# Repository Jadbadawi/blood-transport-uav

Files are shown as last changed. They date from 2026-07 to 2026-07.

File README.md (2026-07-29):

<div align="center">

# Blood-Transport UAV — Joints & Fairings

### Every structural interface that holds the aircraft together, and every aerodynamic surface that covers them

**AVDASI 2 · University of Bristol · Department of Aerospace Engineering · 2024–25**
Albatross Aviation (Company A) · Team 08 · Fuselage Division








</div>

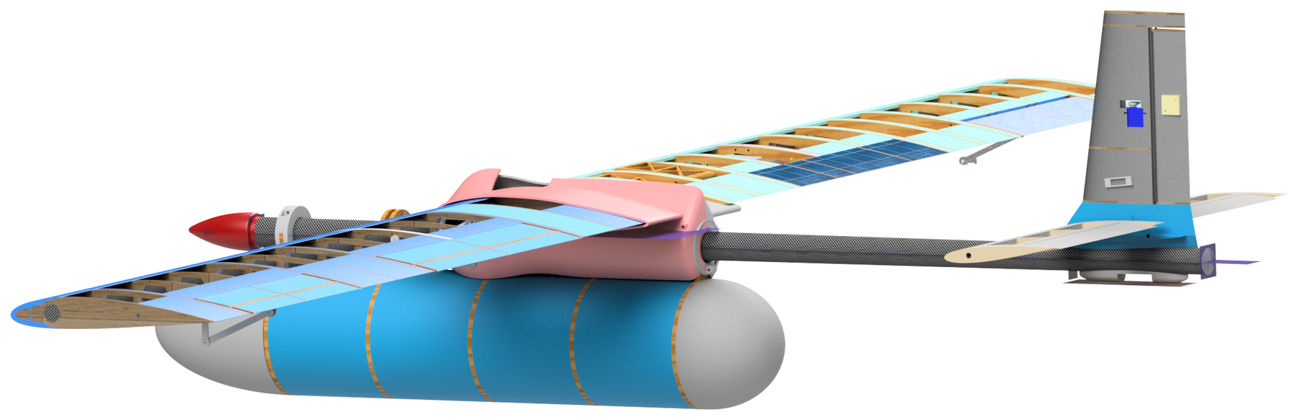
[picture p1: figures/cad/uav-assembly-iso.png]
The UAV as assembled in CAD


<div align="center"><sub><b>Full-vehicle CAD assembly.</b> The pink structure over the wing root is the Fus-MWP fairing; the joint beneath it, the empennage joint at the tail and every fairing on the aircraft are this team's work.</sub></div>

---

## The brief

Design, build and test a UAV capable of moving blood samples rapidly between a rural short
tarmac runway and a hospital test centre — the outbound leg is time-critical, the return by
road is not. Sixty students, three competing companies, one academic year, and a real test
campaign at the end: a wind tunnel entry for aerodynamic data and a load test taken past
the ultimate load case.

Team 08 owned the **joints and fairings** — every structural interface that holds the
aircraft together, and every aerodynamic surface that covers those interfaces. That put us
downstream of six other teams and upstream of the whole airframe: **nothing assembled until
our parts fit.**

**My role:** Fuselage Division Design Team Manager, Team Project Manager, Aero Specialist
and Design Specialist. → [What I personally did](docs/my-contribution.md)

---

## Results at a glance

| | |
|---|---|
| **Ultimate load test** | Survived to **813 N**, past the required ultimate load case |
| **Load response** | Linear throughout — **74 N/mm** centre, **102 N/mm** empennage, no stiffness knee |
| **Governing reserve factor** | **1.95** — 22.2 mm centre bar in bending, at 6g × 1.5 |
| **Observed failure** | Bolt shear-out through the PLA main wing clamp — *an unmodelled path* |
| **Wind tunnel** | 20 m/s; fairings added **+0.09 N** drag, inside the 0.34 N run-to-run scatter |
| **Subassembly mass** | **1,011 g** across 10 parts; fairings were 11.85% of all-up UAV mass |
| **Parts delivered** | 10 flight parts, 100% additively manufactured |

<table>
<tr>
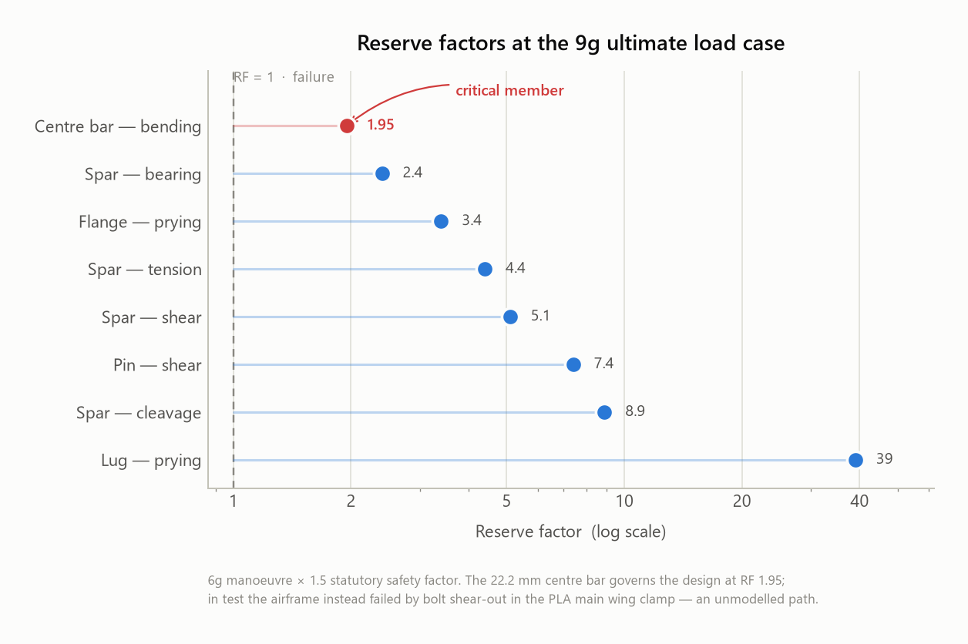
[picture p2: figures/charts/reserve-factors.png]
Reserve factors by check
<td width="50%"></td>
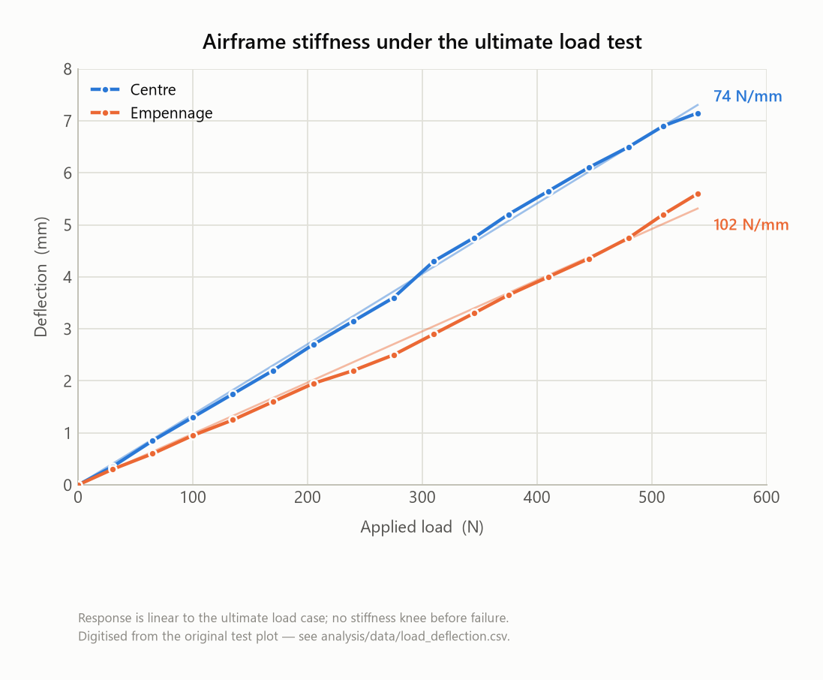
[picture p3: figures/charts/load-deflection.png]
Load vs deflection
<td width="50%"></td>
</tr>
<tr>
<td><sub><b>Eight reserve factors</b>, critical member highlighted. The centre bar at 1.95 was the predicted first failure.</sub></td>
<td><sub><b>Linear to ultimate load</b> — no knee, no progressive softening. The strongest single result in the project.</sub></td>
</tr>
</table>

**The headline engineering result is the gap between two rows of that table.** The stress
work predicted the centre bar would go first. It didn't — the aircraft failed somewhere the
analysis never looked, because no reserve factor had been computed for any 3D-printed part.
That finding, and what it says about where analysis boundaries get drawn, is the most useful
thing in this repository. It is worked through in
[**Structural analysis**](docs/04-structural-analysis.md) and
[**Test campaign**](docs/07-test-campaign.md).

---

## The aircraft

<table>
<tr>
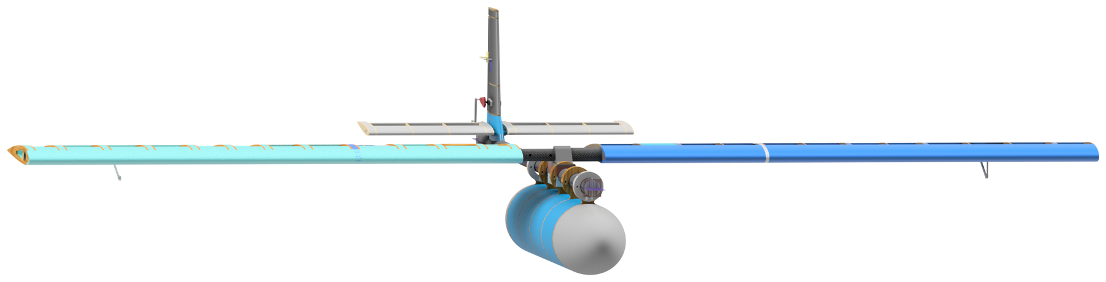
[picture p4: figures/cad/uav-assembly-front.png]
Front view
<td width="33%"></td>
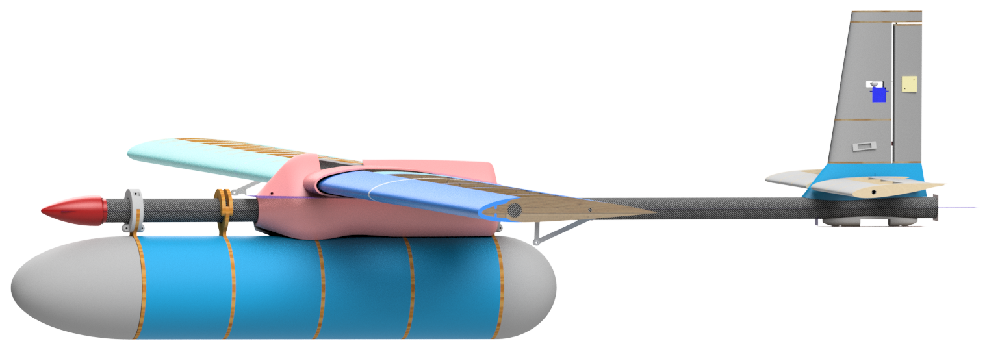
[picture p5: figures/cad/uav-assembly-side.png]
Side view
<td width="33%"></td>
<td width="33%">Isometric view</td>
</tr>
<tr>
<td align="center"><sub>Front</sub></td>
<td align="center"><sub>Side</sub></td>
<td align="center"><sub>Isometric</sub></td>
</tr>
</table>

A 535-file Inventor assembly, including other teams' geometry so the top-level assembly
resolves. Authorship is attributed per-tree in [`cad/README.md`](cad/README.md).

---

## What this team designed

Ten flight parts across two families: **structural joints** that carry load between major
assemblies, and **aerodynamic fairings** that cover the interfaces those joints create.

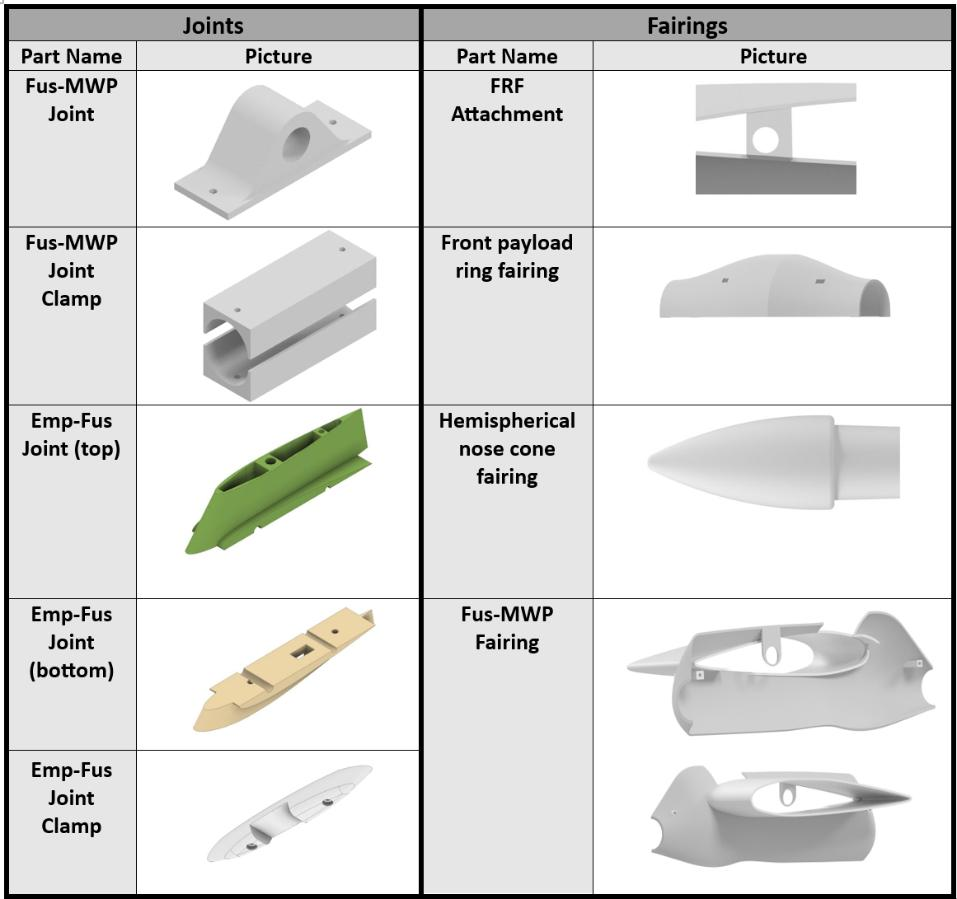
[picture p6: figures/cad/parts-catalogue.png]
The delivered part set


<sub><b>The delivered part catalogue.</b> Every part on this sheet was designed, printed, fitted and flown by Team 08.</sub>

### Structural joints

<table>
<tr>
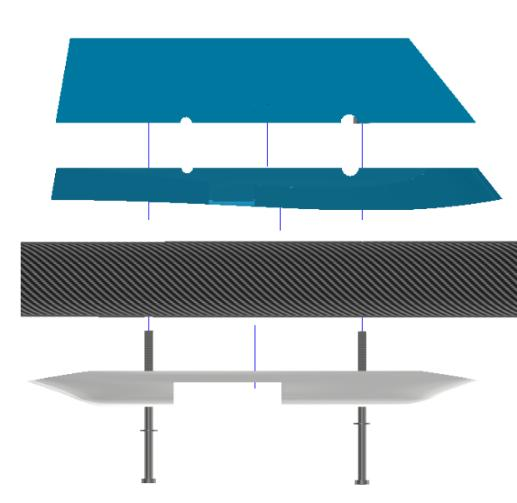
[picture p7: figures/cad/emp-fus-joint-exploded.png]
Empennage-fuselage joint, exploded
<td width="50%"></td>
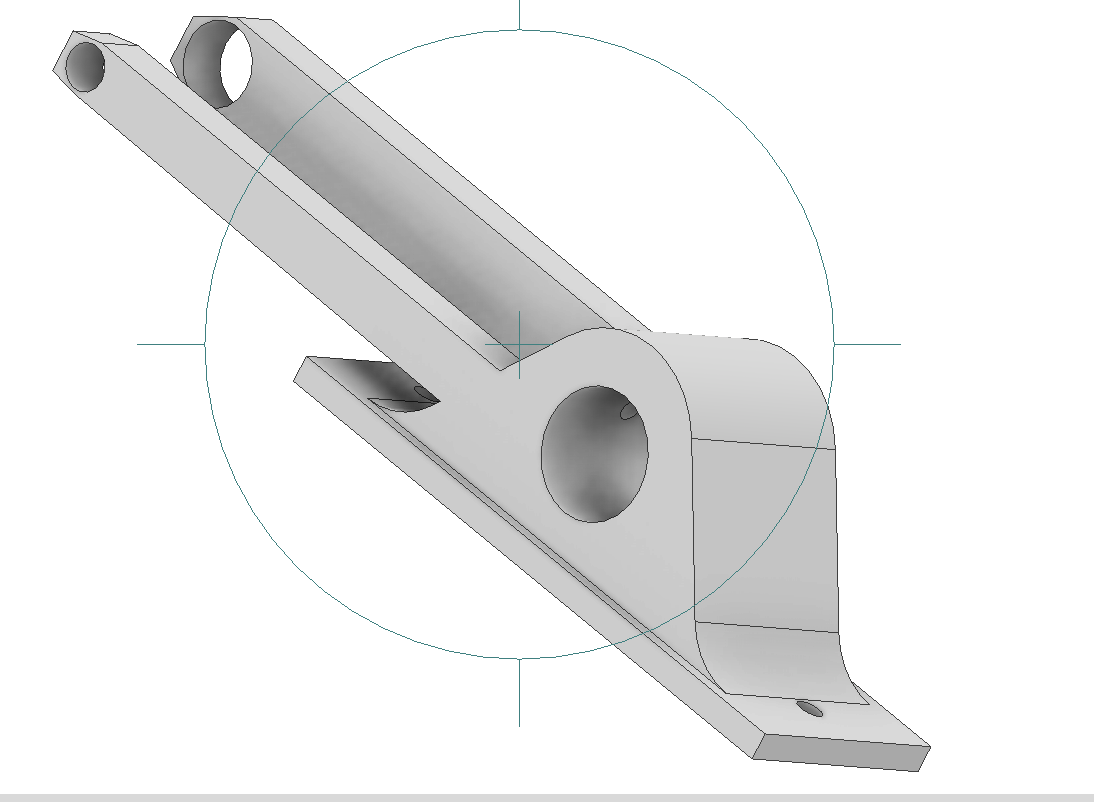
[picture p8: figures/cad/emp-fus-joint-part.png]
Empennage-fuselage joint part
<td width="50%"></td>
</tr>
<tr>
<td><sub><b>Empennage–fuselage joint, exploded.</b> Load passes predominantly into the CFRP fuselage spar, which is sized for it — so the unreinforced PLA joint is acceptable at these load cases.</sub></td>
<td><sub><b>The joint as a single part.</b> Brass inserts take the fasteners; these could work loose under significant lateral load, which the structural test never applied.</sub></td>
</tr>
</table>

<table>
<tr>
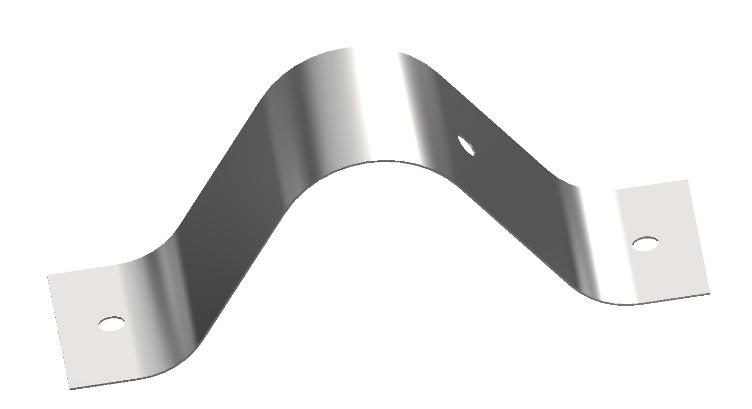
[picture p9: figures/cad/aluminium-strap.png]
Formed aluminium strap
<td width="50%"></td>
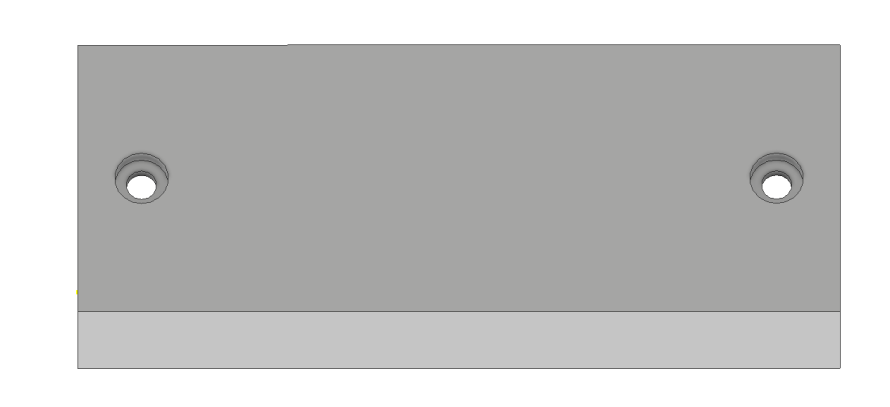
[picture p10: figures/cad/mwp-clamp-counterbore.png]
Main wing plane clamp counterbore
<td width="50%"></td>
</tr>
<tr>
<td><sub><b>Formed 2014A-T3 aluminium strap.</b> This is what protects the <i>upper</i> half of the Fus-MWP joint — load passes into metal and away from the printed plastic.</sub></td>
<td><sub><b>The clamp counterbore.</b> The <i>lower</i> clamp has no such protection, and bolt forces bear directly on PLA. This asymmetry is the direct cause of the eventual failure.</sub></td>
</tr>
</table>

> **The load-path asymmetry above is the whole story of this project in one pair of images.**
> The top half of the joint was protected by metal. The bottom half was not, and nobody
> modelled it.

### Aerodynamic fairings

<table>
<tr>
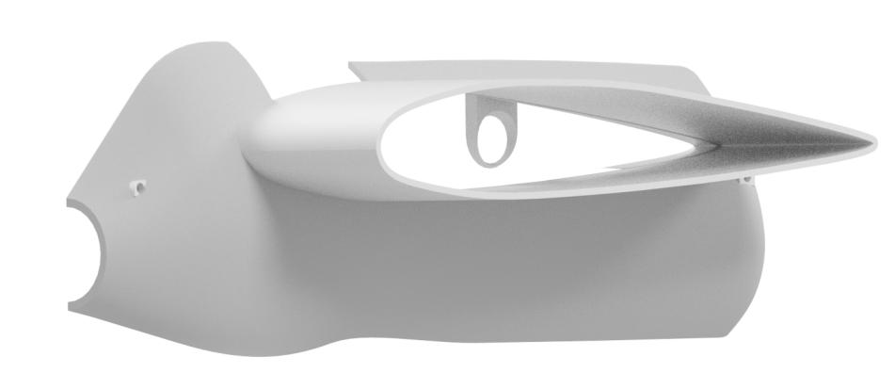
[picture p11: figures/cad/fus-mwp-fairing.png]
Fuselage-main wing plane fairing
<td width="50%"></td>
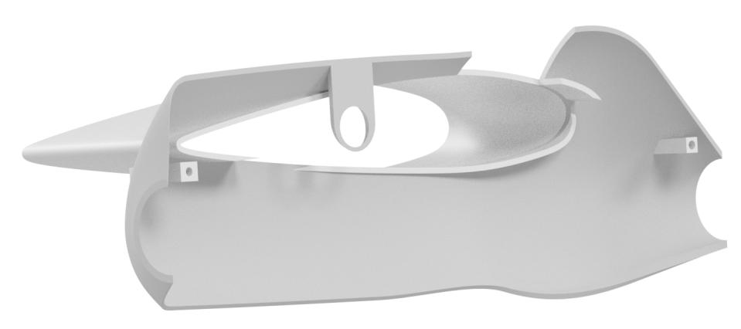
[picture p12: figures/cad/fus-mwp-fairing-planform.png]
Fairing planform
<td width="50%"></td>
</tr>
<tr>
<td><sub><b>The Fus-MWP fairing.</b> Shaped to the same <b>NACA 2414</b> section the wing teams used, so the covering is continuous with the wing it meets.</sub></td>
<td><sub><b>Planform.</b> Maintains laminar flow as far aft as possible and minimises abrupt contour changes.</sub></td>
</tr>
</table>

<table>
<tr>
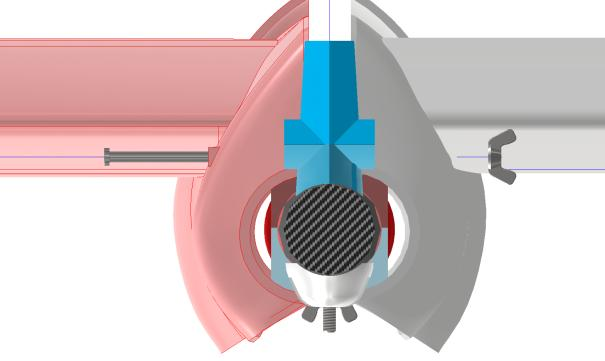
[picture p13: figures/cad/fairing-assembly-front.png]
Fairing assembly, front
<td width="50%"></td>
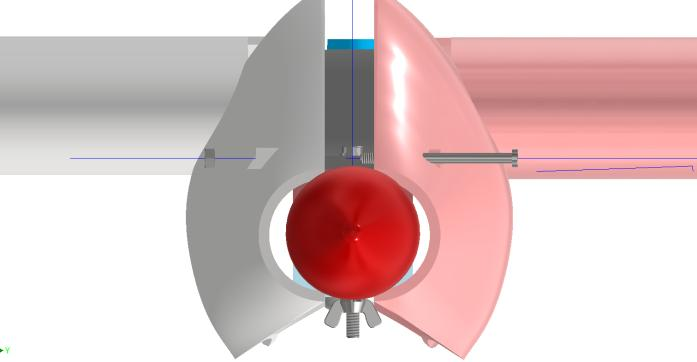
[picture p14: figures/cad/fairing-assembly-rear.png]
Fairing assembly, rear
<td width="50%"></td>
</tr>
<tr>
<td align="center"><sub>Fairing assembly, front</sub></td>
<td align="center"><sub>Fairing assembly, rear</sub></td>
</tr>
</table>

**Why cover anything at all?** The exposed items were the payload rings, the main wing
joint, and roughly **100 mm of cylindrical wing spar**. Using Cayley's minimum-drag shape,
a circular section in 2D produces on the order of **ten times** the drag of an aerofoil
section of the same thickness. A bluff cylinder in clean air is close to the worst thing
that can be left on an aircraft.

But a fairing *adds wetted area*, which adds skin friction — so it is only worth fitting if
it removes more form drag than the friction it introduces. That tension is the central
design argument, set out in full in [Aerodynamics](docs/05-aerodynamics.md).

---

## Concept selection

Before any of the above existed, candidate concepts were scored against weighted criteria.

<table>
<tr>
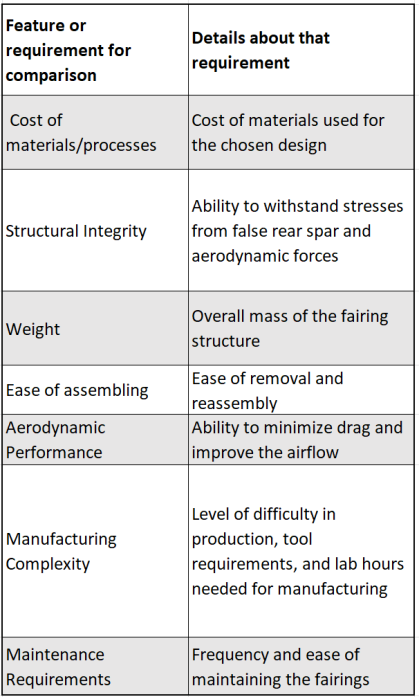
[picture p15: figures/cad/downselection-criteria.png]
Downselection criteria
<td width="50%"></td>
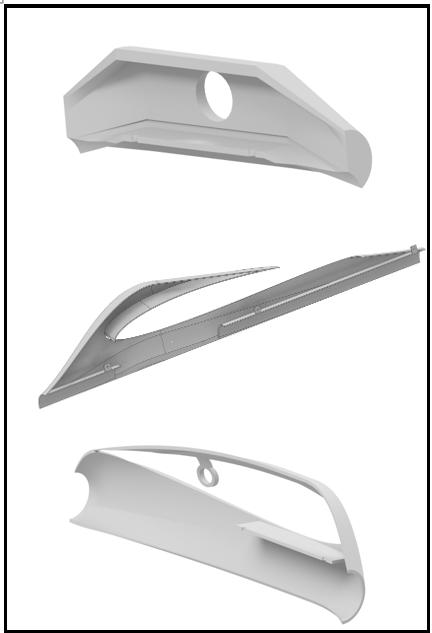
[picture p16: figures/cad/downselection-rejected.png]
Rejected concepts
<td width="50%"></td>
</tr>
<tr>
<td><sub><b>Pairwise criteria weighting</b> feeding a multi-criteria decision analysis.</sub></td>
<td><sub><b>The designs that lost.</b> Kept deliberately — a downselection with no visible rejects is not a decision, it is a preference.</sub></td>
</tr>
</table>

Requirements were tracked to a traceability matrix throughout:

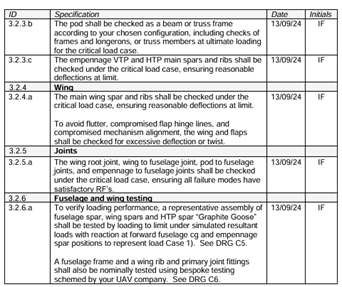
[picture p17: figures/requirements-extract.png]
Requirements extract


→ [Brief & requirements](docs/01-brief-and-requirements.md) · [Concept selection](docs/02-concept-selection.md)

---

## Structural analysis

All checks were run at **6g** with the standard aerospace **1.5** factor on top —
$F_{\text{design}} = 6 \times 1.5 \times F_{1g} = 9 \times F_{1g}$ — and completed in
teaching block 1, **deliberately ahead of detailed design**, so the design team had limits
to work inside rather than an audit to fail afterwards.

<table>
<tr>
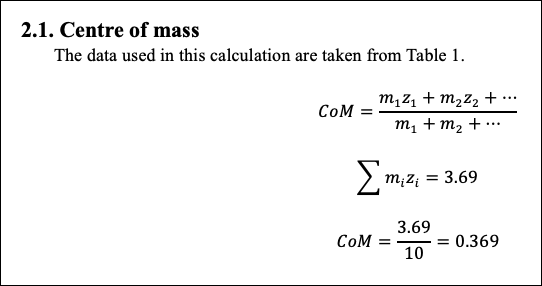
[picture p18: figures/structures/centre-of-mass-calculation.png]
Centre of mass calculation
<td width="50%"></td>
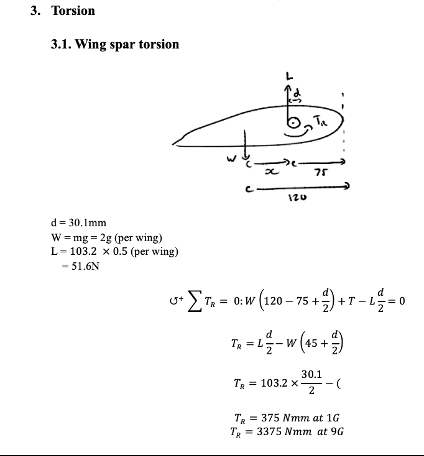
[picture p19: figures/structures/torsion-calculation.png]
Torsion calculation
<td width="50%"></td>
</tr>
<tr>
<td><sub><b>Centre of mass</b> across all subassemblies, cross-checked with the other teams: 0.369 m.</sub></td>
<td><sub><b>Root torsion.</b> Weight acting 120 mm from the leading edge, lift at the rear of the spar: 375 N·mm at 1g, 3375 N·mm at 9g.</sub></td>
</tr>
</table>

| Part | Check | RF |
|---|---|---|
| **Centre bar** | **Bending** | **1.95** |
| Spar | Bearing | 2.4 |
| Flange | Prying | 3.4 |
| Spar | Tension | 4.4 |
| Spar | Shear | 5.1 |
| Pin | Shear | 7.4 |
| Spar | Cleavage | 8.9 |
| Lug | Prying | 39.0 |

Two things in this table are worth more than the pass/fail verdict. The **1.95** is the
design point — conservative by construction, and the predicted first failure. The **39.0**
is a defect: a reserve factor that high is 39× more material than the load requires, and on
a vehicle where mass drives take-off performance that is an unclaimed mass saving. It went
unclaimed.

### Where the mass went

<table>
<tr>
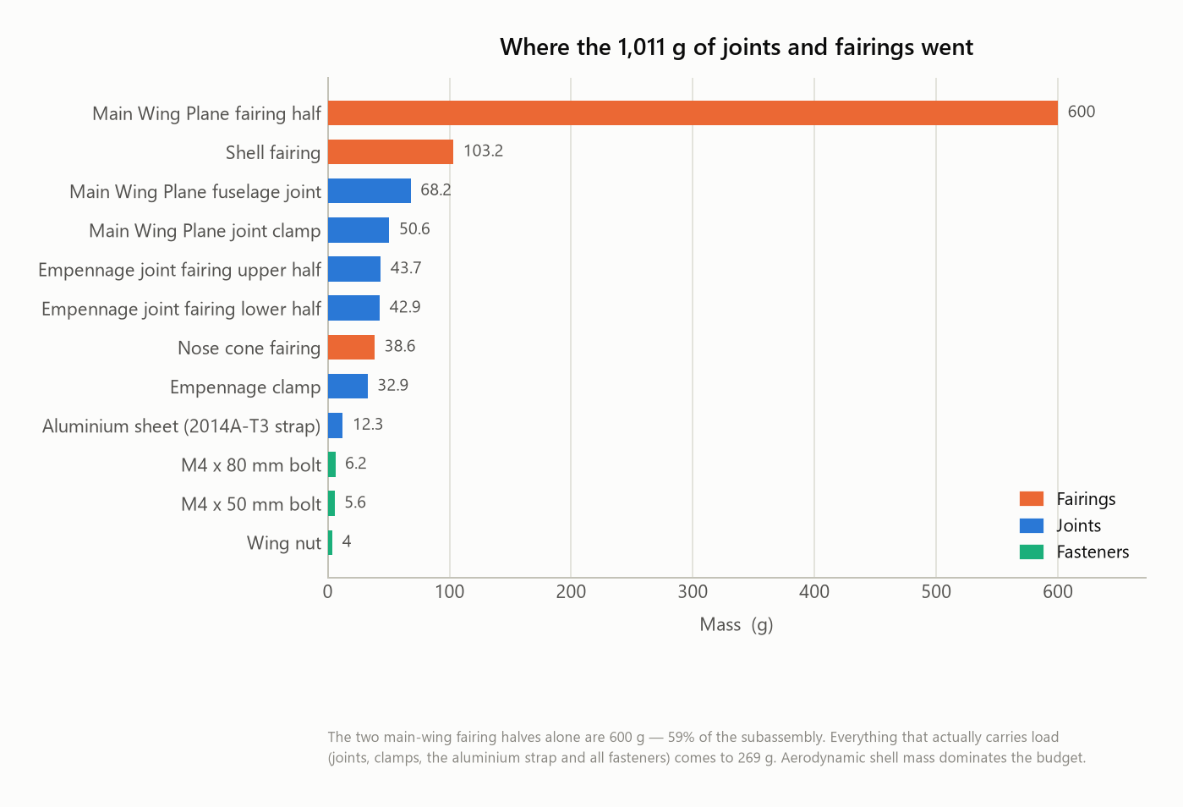
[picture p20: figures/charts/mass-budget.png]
Mass budget
<td width="50%"></td>
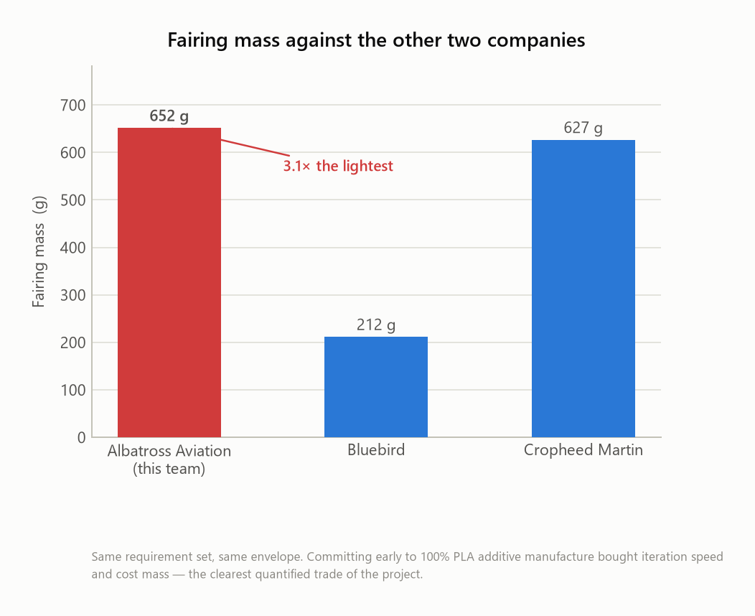
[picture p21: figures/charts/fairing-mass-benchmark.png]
Fairing mass benchmark
<td width="50%"></td>
</tr>
<tr>
<td><sub><b>1,011 g total</b> — but only <b>269 g carries load</b>. The other <b>742 g is aerodynamic shell</b>.</sub></td>
<td><sub><b>3.1× the lightest competitor.</b> All fairings came to 652 g, 11.85% of all-up UAV mass.</sub></td>
</tr>
</table>

The cause was a single early decision: **commit entirely to FDM PLA.** That bought fast
iteration and complex compound curves, both of which the project genuinely needed given how
much the interfaces moved. It cost mass. What makes it a real error rather than an accepted
trade is that **some parts never changed** — the nose cone fairing was stable from early on
and could have been Styrofoam at no schedule risk.

→ [Structural analysis in full](docs/04-structural-analysis.md)

---

## Aerodynamics

At the tunnel speed of 20 m/s: $Re = 4.11 \times 10^5$, $M = 0.058$. Compressibility is
irrelevant, so any drag measured is viscous or form drag — but $Re \approx 4 \times 10^5$ is
low enough that transition is sensitive to surface finish and freestream turbulence, which
is why XFoil and the tunnel were never going to coincide.

<table>
<tr>
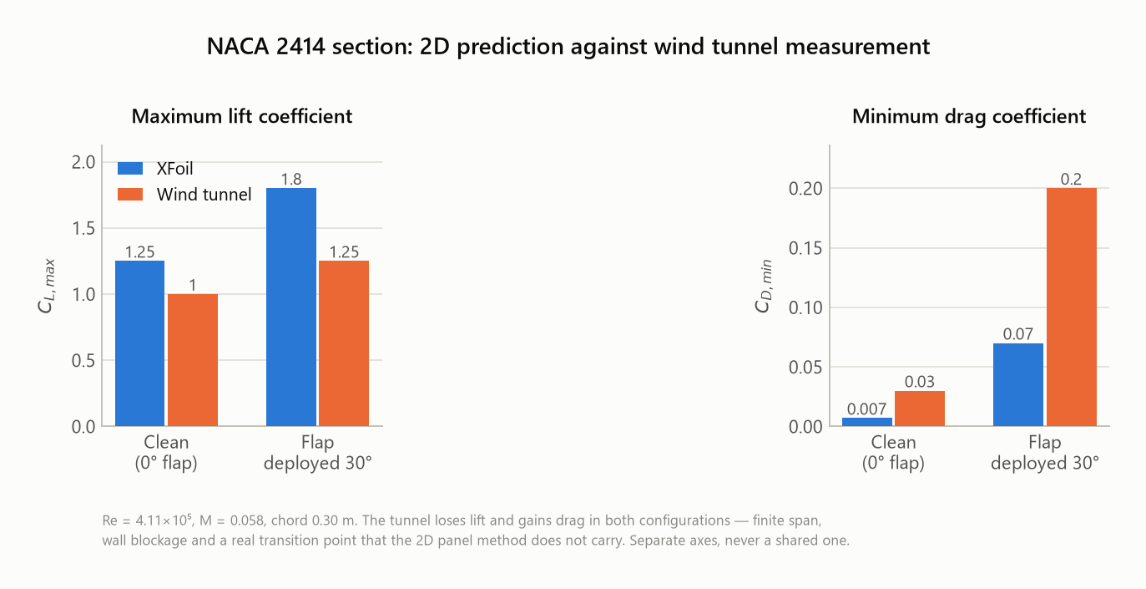
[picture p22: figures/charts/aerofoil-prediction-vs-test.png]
XFoil vs tunnel
<td width="50%"></td>
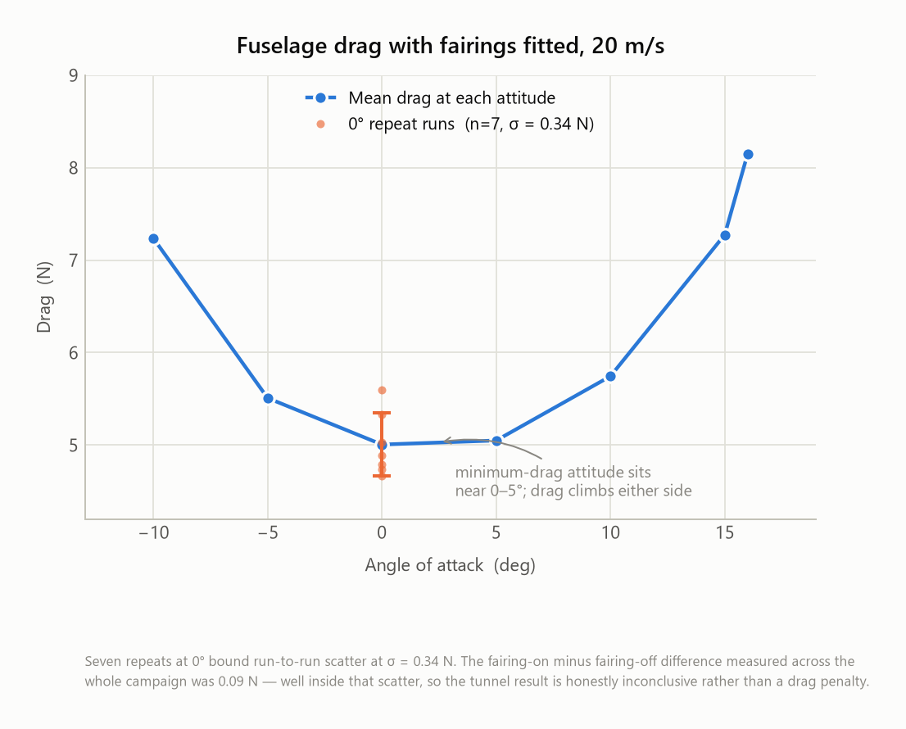
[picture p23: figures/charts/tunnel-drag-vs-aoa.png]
Tunnel drag vs angle of attack
<td width="50%"></td>
</tr>
<tr>
<td><sub><b>XFoil vs wind tunnel</b>, clean and 30° flap. The tunnel loses lift and gains drag in both configurations — consistently, and in the expected direction.</sub></td>
<td><sub><b>Fuselage drag vs angle of attack</b>, with the seven-run 0° repeat scatter that decides how much of this is signal.</sub></td>
</tr>
</table>

| Configuration | Source | C<sub>L,max</sub> | C<sub>D,min</sub> |
|---|---|---|---|
| Clean, 0° flap | XFoil | 1.25 | ~0.007 |
| Clean, 0° flap | Tunnel | **1.00** | **0.030** |
| Flap 30° | XFoil | 1.80 | 0.070 |
| Flap 30° | Tunnel | **1.25** | **0.200** |

**The conclusion is not that XFoil was wrong** — it answered its own question correctly. A
2D, infinite-span, smooth-surface model is a *lower bound on drag and an upper bound on
lift*, and should be read as such. The dominant discrepancy is finite span: tip vortices
generate induced drag and shed bound circulation, a term entirely absent from a 2D solution.

<details>
<summary><b>Original drag polars</b> (click to expand)</summary>

<table>
<tr>
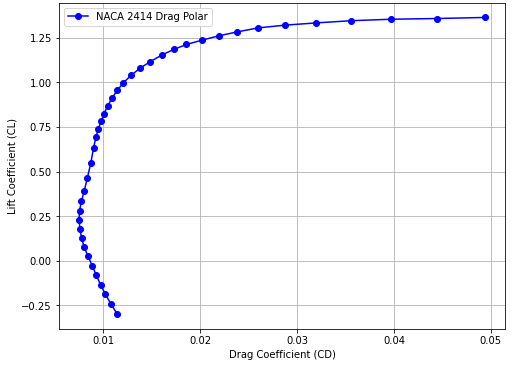
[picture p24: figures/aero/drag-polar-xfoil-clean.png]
XFoil clean
<td width="50%"></td>
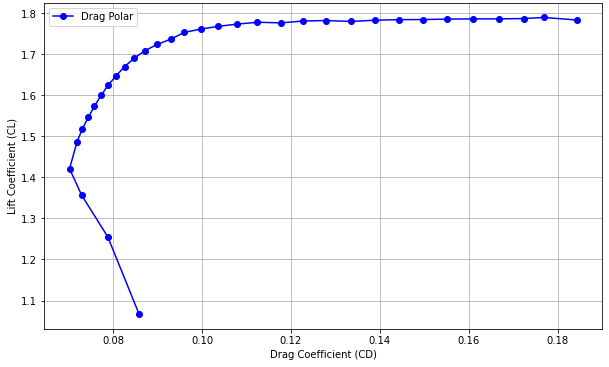
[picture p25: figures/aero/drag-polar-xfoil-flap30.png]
XFoil flap 30
<td width="50%"></td>
</tr>
<tr>
<td align="center"><sub>XFoil, clean</sub></td>
<td align="center"><sub>XFoil, 30° flap</sub></td>
</tr>
<tr>
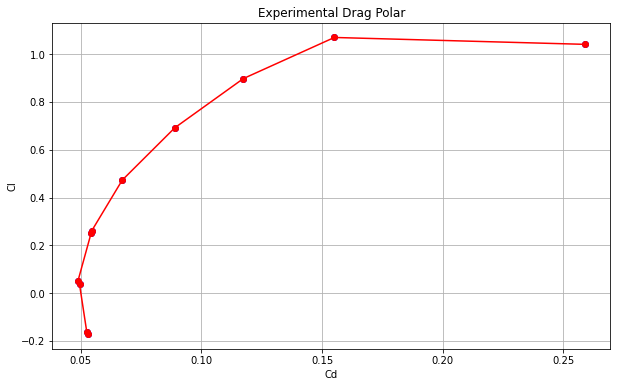
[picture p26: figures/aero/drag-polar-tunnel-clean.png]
Tunnel clean
<td></td>
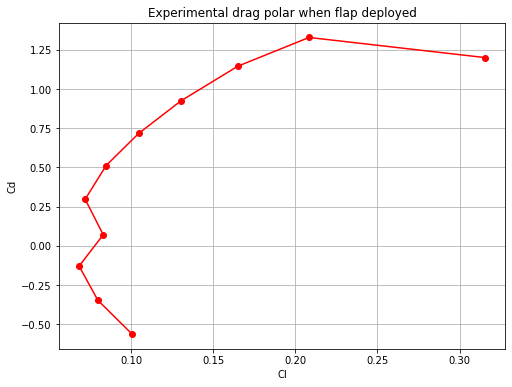
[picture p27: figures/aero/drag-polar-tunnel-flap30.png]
Tunnel flap 30
<td></td>
</tr>
<tr>
<td align="center"><sub>Tunnel, clean</sub></td>
<td align="center"><sub>Tunnel, 30° flap</sub></td>
</tr>
</table>

</details>

### Did the fairings work? The tunnel could not say.

Averaged over the campaign, fairings-on recorded **0.09 N more drag** than fairings-off.
Seven repeat runs at 0° give a run-to-run standard deviation of **σ = 0.34 N** — so the
measured difference is about a quarter of one standard deviation of the measurement noise.
**It is not a resolvable difference.**

<table>
<tr>
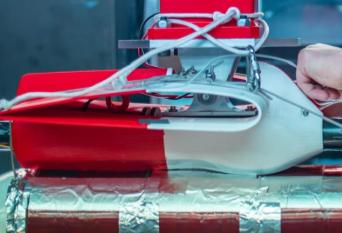
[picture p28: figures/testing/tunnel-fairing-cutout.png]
Fairing cutout in the tunnel
<td width="50%"></td>
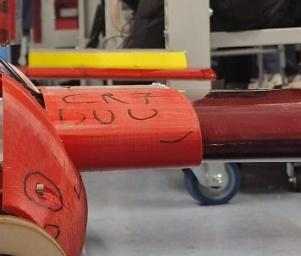
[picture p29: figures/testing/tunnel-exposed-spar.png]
Exposed spar in the tunnel
<td width="50%"></td>
</tr>
<tr>
<td><sub><b>The vertical cutout</b>, added so the fairing would clear the tunnel mounting hardware. A feature added purely for testability degraded the quantity being tested.</sub></td>
<td><sub><b>The exposed spar section.</b> With no wings fitted, the fairing's flanks were open and flow crept inside — a condition that cannot occur on the assembled aircraft.</sub></td>
</tr>
</table>

**The test was structurally biased against the part.** The tunnel could only accommodate the
fuselage, which removed the single largest justification for the fairing — the 100 mm of
exposed spar — from the experiment entirely, while the fairing's cost in extra wetted area
was fully present.

So: **experimentally inconclusive; theoretically the fairing should still reduce drag in
real operation.** A large form-drag benefit was traded for a friction penalty that proved
too small to measure. Closing this properly needs a test with wings fitted, or validated
CFD. Neither was available — and CFD was rejected honestly, because a result nobody on the
team could defend is worse than no result.

→ [Aerodynamics in full](docs/05-aerodynamics.md)

---

## Test campaign

Three events, each answering a different question.

| Test | When | Question | Result |
|---|---|---|---|
| Graphite Goose | TB-1 | Do the joints work as predicted at limit load? | Pass — behaved as analysed |
| Ultimate load test | 5 Mar 2025 | Does the airframe survive past ultimate load? | Pass to **813 N**, then failed in an unpredicted mode |
| Wind tunnel | TB-2 | Do the fairings reduce drag? | **Inconclusive** — the configuration could not answer it |

<table>
<tr>
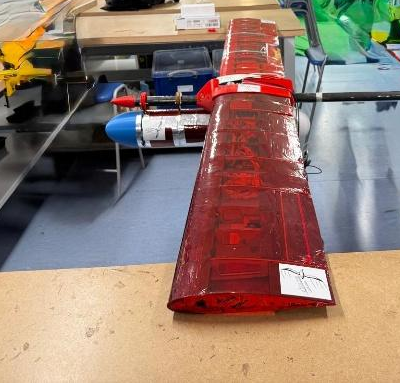
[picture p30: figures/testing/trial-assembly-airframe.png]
Trial assembly
<td width="50%"></td>
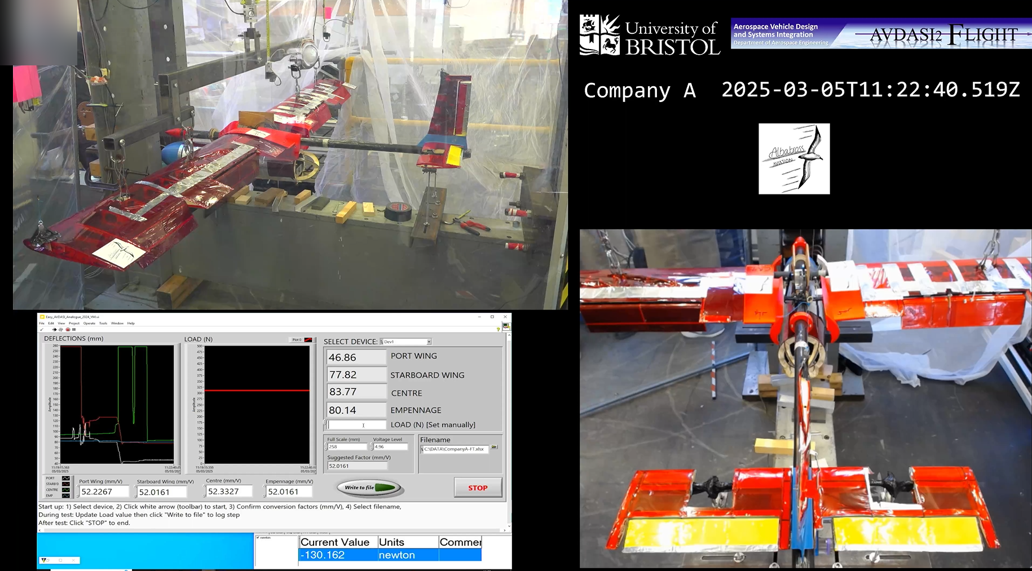
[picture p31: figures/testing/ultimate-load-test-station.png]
Ultimate load test station
<td width="50%"></td>
</tr>
<tr>
<td><sub><b>The practice build.</b> Nothing assembled until our parts fitted, so a trial assembly was not optional.</sub></td>
<td><sub><b>Load test station, 5 March 2025.</b> The loaded airframe in the rig, LabVIEW deflection channels at port wing, starboard wing, centre and empennage.</sub></td>
</tr>
</table>

### Then it failed somewhere else

Sensors were removed after ultimate load was reached, to protect them. Loading continued.
The recorded load went **813 N → 804 N → 764 N**. A load drop with no visible or audible
event means something has yielded — but nothing was obvious from outside, so the aircraft
was disassembled and inspected.

**The centre bar — RF 1.95, the predicted failure point — was undamaged.** It was inspected
specifically because it was expected to fail, and showed no deformation at all.

<table>
<tr>
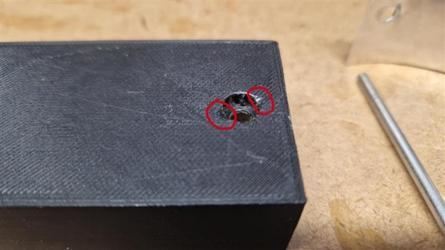
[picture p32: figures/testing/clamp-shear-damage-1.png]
Clamp shear damage
<td width="33%"></td>
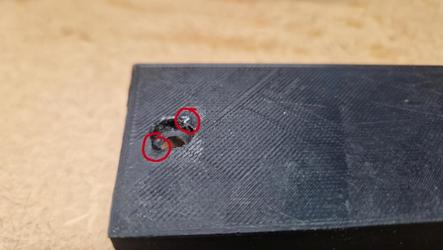
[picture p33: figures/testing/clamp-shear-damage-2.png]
Clamp shear damage, second view
<td width="33%"></td>
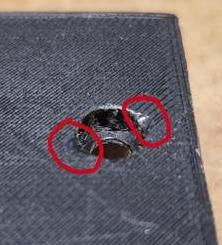
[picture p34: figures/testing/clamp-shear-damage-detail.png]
Shear damage detail
<td width="33%"></td>
</tr>
</table>

<sub><b>Bolt shear-out through the PLA main wing joint clamp.</b> The wing nut has pulled down into the counterbore cavity and the bolt has begun working through the remaining thin section of printed plastic.</sub>

### Two causes, and neither is arithmetic

**1 · The analysis had no term for this mode.** No reserve factor was ever computed for any
3D-printed part. Every check in the table above is a check on a metallic member — the
aluminium centre bar, the CFRP spar, the aluminium strap and its fasteners. Printed PLA
components were treated, per requirement 2.5.2.a, as non-structural formers. This is a
**scoping** failure, and a common one in practice: the analysis boundary was drawn around
the parts the method knew how to handle, and never revisited when a printed part ended up in
a primary load path.

**2 · The wrong clamp was fitted.** Two variants existed *deliberately* — a wind tunnel
clamp with an 8 mm counterbore for a flanged bronze bush, and a structural test clamp with
solid material under the wing nut. The **wind tunnel clamp was fitted for the structural
test**, because swapping it meant disassembling the pod and there was not enough time. The
aircraft was loaded with a cavity directly beneath the wing nut.

> **The design anticipated this problem and solved it. Build configuration control did not
> carry the solution through to the day.** The correct part existed and was not fitted.

Both things are true at once: the predictions that *were* made were sound — linear response
to ultimate load and an undamaged centre bar confirm the whole analysis chain — and the
predictions did not cover the aircraft. Correct answers to the wrong question.

→ [Test campaign in full](docs/07-test-campaign.md)

---

## Project management

I ran the Fuselage Division design team and the team project plan, so the planning artefacts
are part of the engineering record rather than an appendix to it.

<table>
<tr>
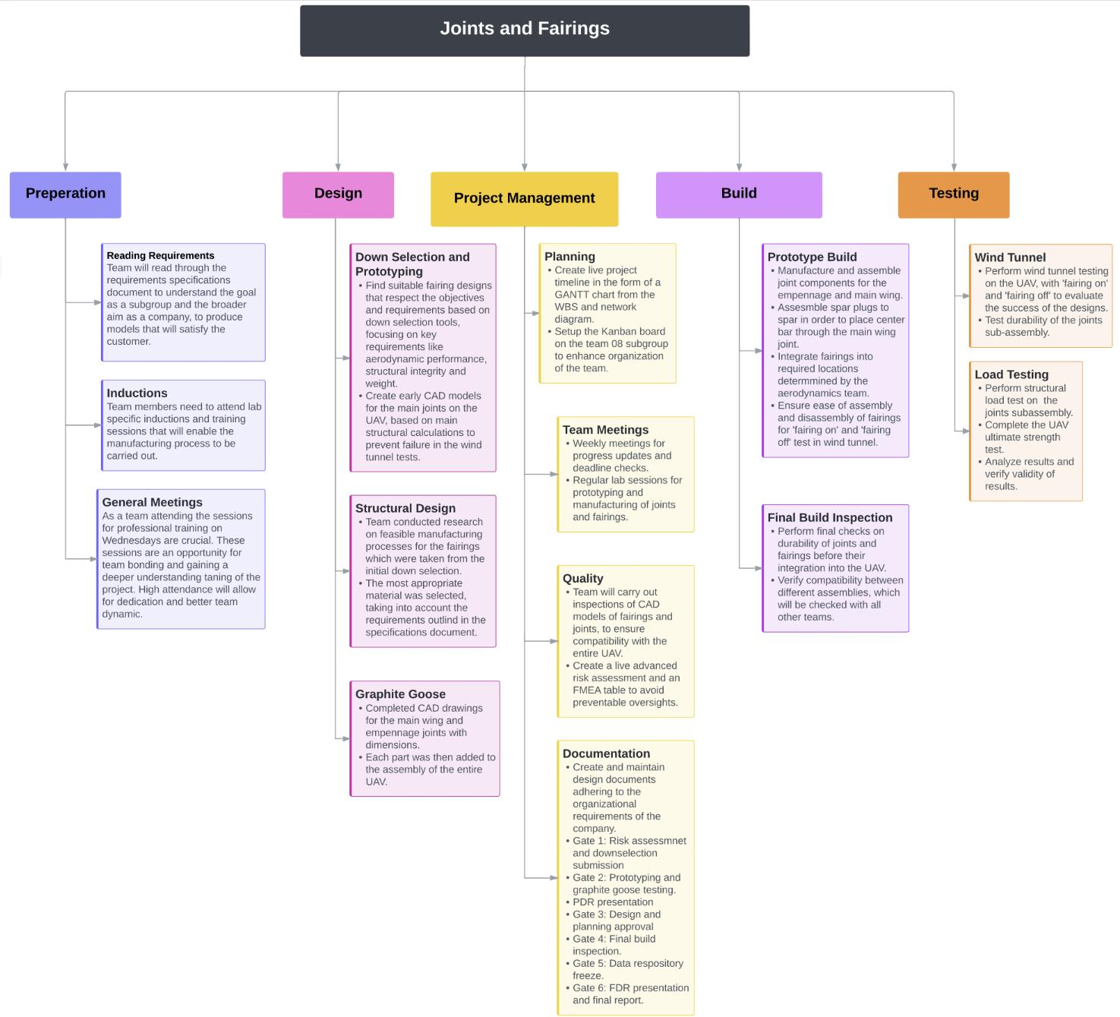
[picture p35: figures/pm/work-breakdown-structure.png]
Work breakdown structure
<td width="50%"></td>
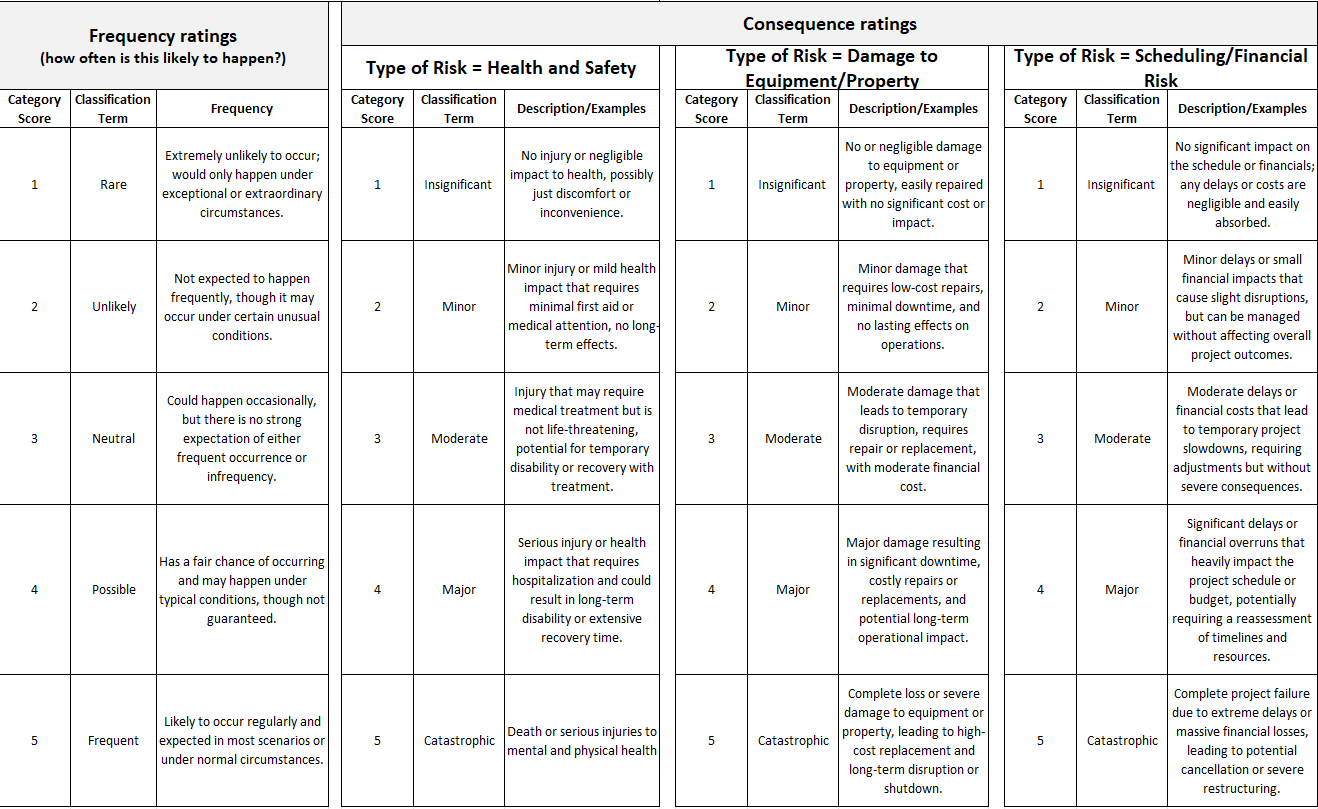
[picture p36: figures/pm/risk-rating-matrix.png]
Risk rating matrix
<td width="50%"></td>
</tr>
<tr>
<td align="center"><sub>Work breakdown structure</sub></td>
<td align="center"><sub>Risk rating matrix</sub></td>
</tr>
</table>

<details>
<summary><b>Gantt charts, network diagrams and the risk register</b> (click to expand)</summary>

<table>
<tr>
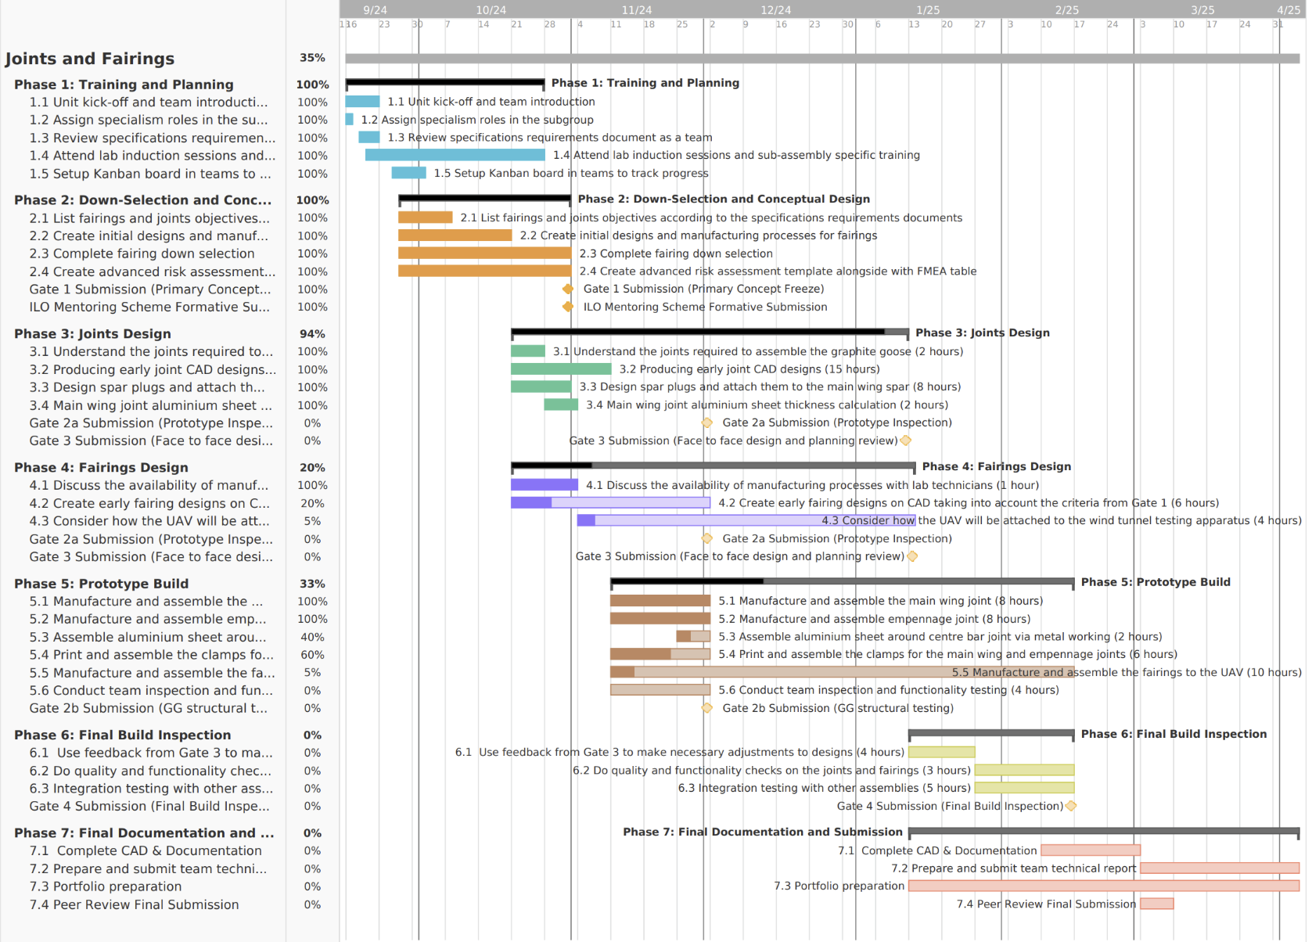
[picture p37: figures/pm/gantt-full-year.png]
Full year Gantt
<td width="50%"></td>
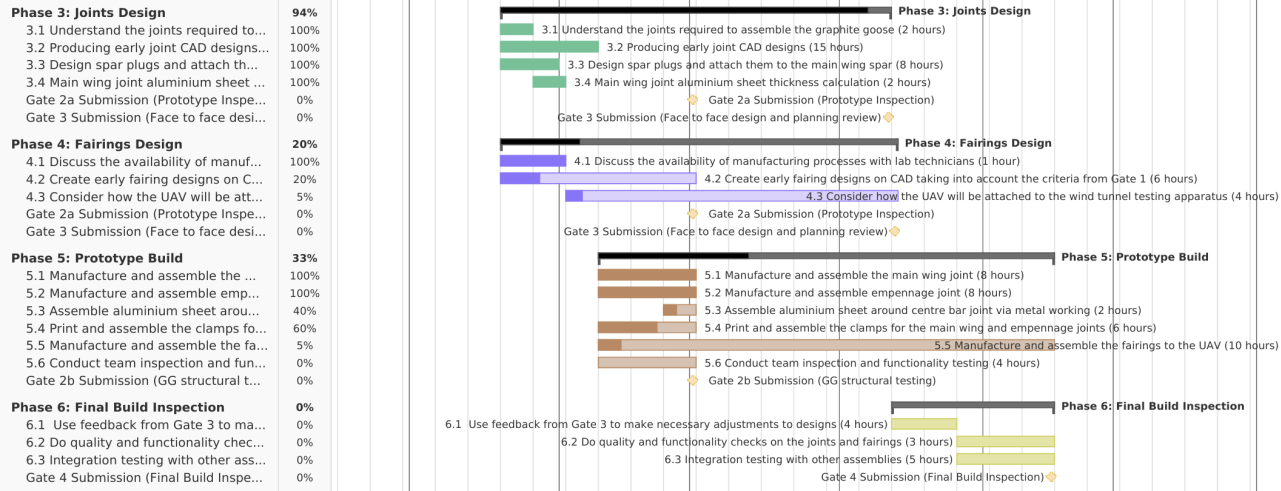
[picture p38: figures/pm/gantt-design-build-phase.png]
Design and build phase Gantt
<td width="50%"></td>
</tr>
<tr>
<td align="center"><sub>Full academic year</sub></td>
<td align="center"><sub>Design and build phase</sub></td>
</tr>
<tr>
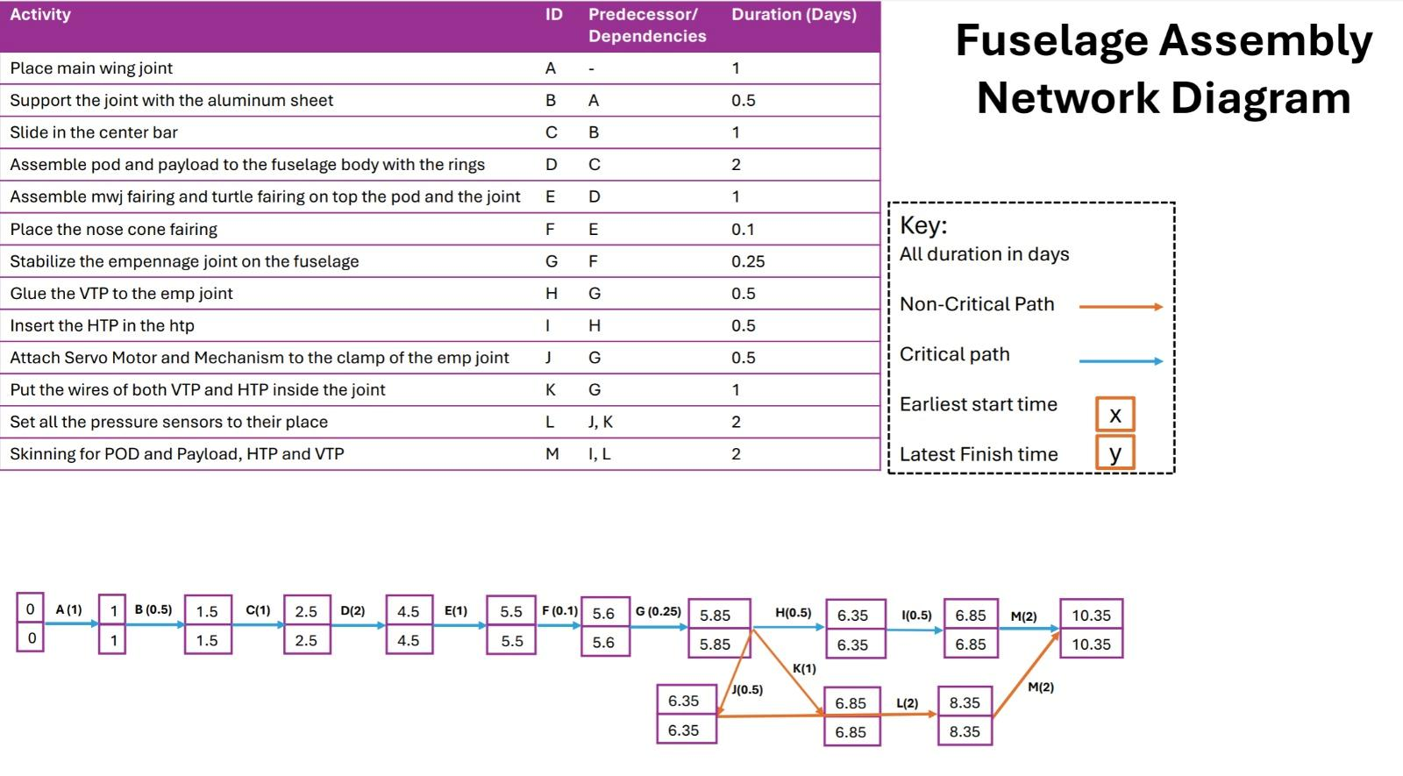
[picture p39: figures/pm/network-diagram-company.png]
Company network diagram
<td></td>
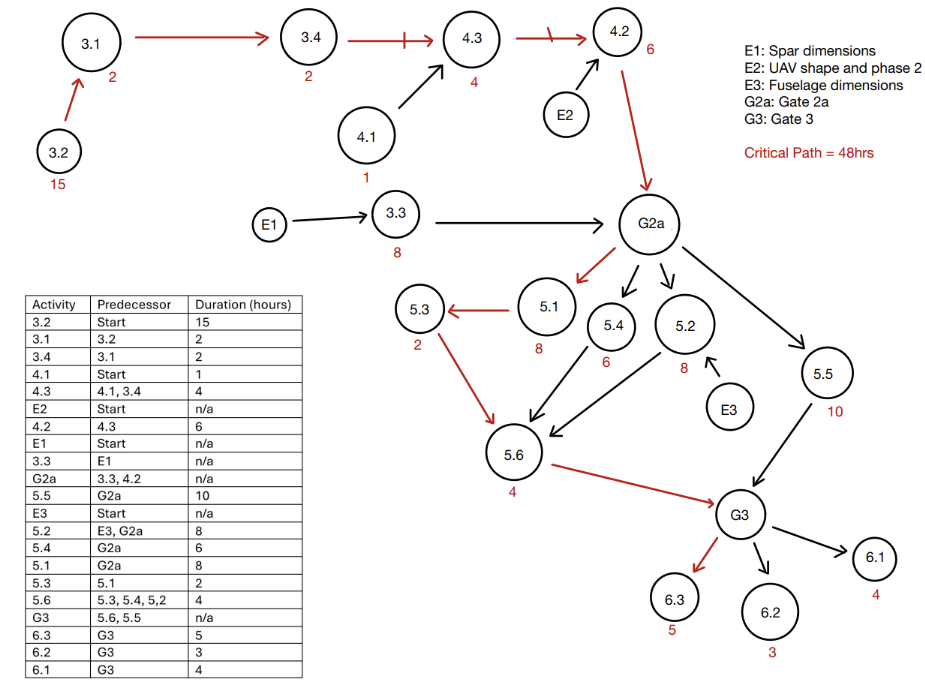
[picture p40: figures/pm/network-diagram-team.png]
Team network diagram
<td></td>
</tr>
<tr>
<td align="center"><sub>Company-level critical path</sub></td>
<td align="center"><sub>Team-level critical path</sub></td>
</tr>
</table>

Risk register

</details>

→ [Project management & risk](docs/08-project-management-and-risk.md) · [Lessons learned](docs/09-lessons-learned.md)

---

## Documentation

| # | Page | What it covers |
|---|---|---|
| 01 | [Brief & requirements](docs/01-brief-and-requirements.md) | Mission, load cases, and a full requirements traceability matrix |
| 02 | [Concept selection](docs/02-concept-selection.md) | Pairwise criteria weighting, MCDA, and the designs that were rejected |
| 03 | [Detailed design](docs/03-detailed-design.md) | Every joint, clamp and fairing — geometry, load path, interfaces |
| 04 | [Structural analysis](docs/04-structural-analysis.md) | Load cases, reserve factors, centre-bar sizing, the aluminium strap |
| 05 | [Aerodynamics](docs/05-aerodynamics.md) | XFoil vs tunnel, drag decomposition, why the fairing is shaped that way |
| 06 | [Manufacturing & integration](docs/06-manufacturing-and-integration.md) | Additive process, tolerance stack-ups, brass inserts, the CAD rebuild |
| 07 | [Test campaign](docs/07-test-campaign.md) | Graphite Goose, ultimate load test, wind tunnel entry, failure analysis |
| 08 | [Project management & risk](docs/08-project-management-and-risk.md) | WBS, Gantt, critical path vs actual, the risk register |
| 09 | [Lessons learned](docs/09-lessons-learned.md) | An honest retrospective, including what the design reviews got right |
| — | [My contribution](docs/my-contribution.md) | Scope of my own work across four roles |

---

## Repository layout

```
├── cad/            Inventor 2024 native model — full UAV, 535 files
│                   └── see cad/README.md for the part index and who drew what
├── docs/           The engineering write-up, above
├── analysis/
│   ├── data/       Source data as CSV, each with a provenance header
│   └── scripts/    make_charts.py — regenerates every chart from that data
├── figures/        CAD renders, test photography, report figures, charts
│                   └── see figures/README.md for the figure index
└── reference/      Issued test plan and drawing samples
```

### Reproducing the analysis

Every derived chart in `figures/charts/` is generated from the CSVs in `analysis/data/`.
Nothing is hand-drawn:

```bash
pip install matplotlib numpy
python analysis/scripts/make_charts.py
```

Each CSV carries a header stating where its numbers came from and how much they can be
trusted — measured, quoted from the report, or digitised off a plot.
`load_deflection.csv` is digitised and says so; treat it as a stiffness fit, not as primary
measurement.

### Tests

```bash
pip install pytest
python -m pytest analysis/scripts/
```

The suite checks that every dataset parses and records its own provenance, that the
headline numbers quoted above are actually the ones in the data (1,011 g total, RF 1.95 on
the centre bar, the 74 / 102 N/mm stiffnesses), that every row of the mass table is
internally consistent, and that each chart still regenerates. It also asserts that the
digitised load-deflection curve stops at 540 N — so it can never be mistaken for, or quoted
as, the 813 N ultimate load result.

---

## Tools

Autodesk Inventor 2024 · XFoil · Bambu Studio / FDM (PLA) · Python (matplotlib, numpy) ·
low-speed wind tunnel with a six-component balance · LabVIEW load and deflection acquisition

---

## Notes on this repository

- **Team work, individually documented.** The subassembly was delivered by six people. This
  repository is written from my own vantage point and my contribution is scoped explicitly
  in [`docs/my-contribution.md`](docs/my-contribution.md); teammates are referred to by role
  rather than by name, since they did not consent to publication.
- **Other teams' CAD is included** so the top-level assembly resolves. Authorship is
  attributed per-tree in [`cad/README.md`](cad/README.md).
- **Two photographs were altered for privacy** and one report figure excluded for
  copyright. Both are recorded in [`figures/README.md`](figures/README.md).
- Figures are reproduced from Team 08's own technical report. Third-party teaching material
  that appeared in that report has been left out.

## Licence

Documentation and figures: [CC BY-NC 4.0](LICENSE). CAD geometry is coursework produced
under University of Bristol supervision and is published here for portfolio purposes —
please do not submit it as your own work. To cite this work, see
[`CITATION.cff`](CITATION.cff).

---

<div align="center">

**Jad El Badaoui** · BEng Aerospace Engineering, University of Bristol

</div>

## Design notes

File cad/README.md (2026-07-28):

# CAD Repository

Autodesk Inventor 2024 native files for the complete Albatross Aviation UAV, as
frozen at the end-of-project data repository freeze.

> **Opening the model.** Open `Full Assembly (1)/FullAssembly (1).iam`. The
> assembly resolves its children by *relative* path, so the folder structure
> below must be kept intact — moving or renaming subfolders will break the
> references. If Inventor asks to resolve a missing link, point it at the
> `Full Assembly (1)` directory.

---

## What is in here, and who drew it

This was a 60-student company split into subassembly teams. **Team 08 (Joints &
Fairings) authored the `JointsAndFairings` tree** — that is the work this
portfolio documents. The remaining trees are the other teams' subassemblies,
included because the top-level assembly will not open without them and because
integrating them into a single resolvable model was itself one of Team 08's
contributions.

| Path | Subassembly | Authored by |
|---|---|---|
| `Full Assembly (1)/JointsAndFairings/` | **Joints, clamps, fairings** | **Team 08 — this team** |
| `Full Assembly (1)/FullAssembly (1).iam` | Top-level integration assembly | Team 08 (assembled) |
| `Full Assembly (1)/P Wing/` | Port wing, flap, aileron | Port wing team |
| `Full Assembly (1)/S Wing/` | Starboard wing | Starboard wing team |
| `Full Assembly (1)/S Flap and Aileron/` | Starboard control surfaces | Starboard wing team |
| `Full Assembly (1)/HTP&elevator/` | Horizontal tailplane, elevator | Empennage team |
| `Full Assembly (1)/VTP/` | Vertical tailplane | Empennage team |
| `Full Assembly (1)/Pod/` | Payload pod, rings, nose/rear cones | Pod team |

`A-Fus Wind Tunnel Test Plan.pdf` and `Full Assembly (1)/VTP/Drawings/` are the
issued test plan and a sample of the formal 2D drawing set.

---

## Team 08 part index

Ten parts went onto the flying article. Files live under
`Full Assembly (1)/JointsAndFairings/`.

### Joints and clamps

| Part | File | Material | Mass |
|---|---|---|---|
| Fus-MWP joint | `Joints/8P - MainWing Joint.ipt` | PLA + 2014A-T3 strap | 68.2 g |
| Fus-MWP joint clamp (×2) | `Joints/8P-MainWingJoint Clamp.ipt` | PLA | 25.3 g ea. |
| Aluminium bearing strap | `Aluminum Sheet.ipt` | 2014A-T3 sheet | 12.3 g |
| Emp-Fus joint, top + bottom | `Joints/Final emp joint.ipt` | PLA + brass inserts | 43.7 / 42.9 g |
| Emp-Fus clamp (servo housing) | `Joints/updated emp clamp for servo.ipt` | PLA | 32.9 g |

### Fairings

| Part | File | Material | Mass |
|---|---|---|---|
| Fus-MWP fairing (2 halves, printed in 4) | `Port/8P_PortFairing.ipt`, `StarBoard/8P_001_StarboardFairingFinal.ipt` | PLA | 300 g ea. |
| Hemispherical nose cone fairing | `NoseCone Fairing/noseconefairing.ipt` | PLA | 38.6 g |
| Shell fairings (×2) — front payload ring and fuselage | `FrontRingFairing.ipt`, `Fuselage JF.ipt` | PLA | 51.6 g ea. |
| FRF (false rear spar) attachment | integrated into the main fairing | PLA | — |

The published mass table records the two shell fairings as a single line item at
51.6 g each; it does not distinguish which is which, so they are grouped here.

Full mass breakdown, including fasteners:
[`analysis/data/subassembly_mass.csv`](../analysis/data/subassembly_mass.csv).

---

## Part numbering convention

The company used a positional scheme. Team 08's parts carry the `8` prefix:

```
8P - MainWing Joint          8  P    - <descriptive name>
                             │  └── P = part, A = assembly, D = drawing, JF = joints/fairings
                             └───── originating team number (08)
```

Other teams used a fuller dotted form, e.g.
`1P.01.01.01-HB-Rib1` → team 01, part, assembly 01, sub 01, item 01, author
initials `HB`. The inconsistency between the two schemes is one of the
configuration-management lessons recorded in
[`docs/09-lessons-learned.md`](../docs/09-lessons-learned.md).

---

## What was removed before publishing

- **`OldVersions/` directories** (26 folders, 207 files) — Inventor's automatic
  backup copies. No design intent lives in them.
- **A duplicated nested `JointsAndFairinsg (1)/` tree** — an artefact of the
  mid-project CAD rebuild described in
  [`docs/06-manufacturing-and-integration.md`](../docs/06-manufacturing-and-integration.md),
  where the same parts appeared three levels deep.

535 files and 178 MB remain. Nothing that the top-level assembly references was
removed.

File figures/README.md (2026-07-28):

# Figure Index

## `charts/` — generated

Produced by [`analysis/scripts/make_charts.py`](../analysis/scripts/make_charts.py)
from the CSVs in [`analysis/data/`](../analysis/data/). Regenerate with
`python analysis/scripts/make_charts.py`. Do not edit these by hand — change the
data or the script.

| File | Shows |
|---|---|
| `reserve-factors.png` | All eight reserve factors, critical member highlighted |
| `load-deflection.png` | Load vs deflection with fitted stiffness (74 / 102 N/mm) |
| `aerofoil-prediction-vs-test.png` | XFoil vs wind tunnel, C<sub>L,max</sub> and C<sub>D,min</sub> |
| `tunnel-drag-vs-aoa.png` | Fuselage drag vs angle of attack, with 0° repeat scatter |
| `mass-budget.png` | Subassembly mass by part, split structural vs aerodynamic |
| `fairing-mass-benchmark.png` | Fairing mass against the two competing companies |

## `cad/` — model renders and part views

`uav-assembly-iso/side/front.png` are Inventor renders of the full vehicle,
autocropped. `parts-catalogue.png` is the delivered part set. The remainder are
individual parts, assembly sequences and downselection material.

## `testing/` — test campaign photography

`ultimate-load-test-station.png` is the load test station on 5 March 2025.
`clamp-shear-damage-*.png` are the post-test inspection photographs of the
failed main wing joint clamp. `tunnel-*.png` are wind tunnel configuration
photographs. `trial-assembly-airframe.png` is the practice build.

## `structures/`, `aero/`, `pm/` — figures from the technical report

Original figures as they appeared in Team 08's A2 technical report:
hand-derived calculations, the original drag polars, mass tables, and the
project management artefacts (WBS, Gantt charts, network diagrams, risk
register and rating matrix).

`structures/load-deflection-original.png` is the original test plot that
`charts/load-deflection.png` was digitised from — kept so the derived chart can
be checked against its source.

---

## Editorial notes

Two figures were altered before publishing, both for privacy. This repository is
public and the people in these photographs did not consent to appearing in it:

- **`testing/ultimate-load-test-station.png`** — a small reflected face in the
  top-left rig panel has been irreversibly blurred.
- **`testing/trial-assembly-airframe.png`** — cropped from a wider photograph to
  remove two identifiable people, keeping the airframe on the bench.

One figure from the technical report was **excluded**: a drag breakdown diagram
reproduced from university teaching material. It was used in the report under
academic fair dealing, which does not extend to republication here. The concept
it illustrates is set out in words in
[`docs/05-aerodynamics.md`](../docs/05-aerodynamics.md).

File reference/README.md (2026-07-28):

# Reference Documents

Primary source material behind the write-up in [`docs/`](../docs/).

| File | What it is |
|---|---|
| `Team08_A2TechnicalReport.pdf` | Team 08's full A2 technical report — the primary source for everything in this repository. 35 pages covering design and manufacturing review, structures, aerodynamics, project management, risk assessment, and the Gate 3 / Gate 4 review records. |
| `A-Fus Wind Tunnel Test Plan.pdf` | The issued test plan for the fuselage wind tunnel entry. |
| `drawings/` | Sample of the company's formal 2D drawing set (VTP body, ribs and master assembly) — included to show the drawing standard and numbering convention in use. Authored by the empennage team. |

## Attribution within the technical report

The report is a six-person team document. My own written contributions were the
**Project Management** section in full, the **Aerodynamics** section in full,
and **Design and Manufacturing 3.1–3.2** (downselection and subassembly design).
The Structures sections and Design and Manufacturing 3.3–3.5 were written by
teammates. See [`docs/my-contribution.md`](../docs/my-contribution.md).

## A note on what is not here

The individual reflective portfolio submitted alongside this report is not
published. It contains personal identifiers, third-party performance
information, and interpersonal detail about teammates who did not consent to
publication. The professionally relevant content from it — roles held, tasks
owned, and what I would do differently — is written up in
[`docs/my-contribution.md`](../docs/my-contribution.md) and
[`docs/09-lessons-learned.md`](../docs/09-lessons-learned.md) instead.

Teaching material reproduced in the technical report under academic fair dealing
has also been excluded from the figure set.

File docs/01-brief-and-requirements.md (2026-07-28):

# 01 · Brief and Requirements

[← Back to overview](../README.md) · [Next: Concept selection →](02-concept-selection.md)

---

## The mission

Albatross Aviation was commissioned to produce a UAV that transports blood
samples for emergency use. Three constraints shaped everything downstream:

1. **Short rural tarmac runways.** Take-off performance is limited, so all-up
   mass is a first-order design driver rather than a nice-to-have.
2. **The outbound leg is time-critical; the return by road is not.** The
   vehicle is optimised for speed to the test centre. Minimising drag is
   therefore the dominant aerodynamic objective — not endurance, not glide
   ratio.
3. **The airframe must survive a real load test.** Predictions made in the first
   teaching block were checked against a physical test taken past the ultimate
   load case, and against a wind tunnel entry.

That second point is what justifies the fairings existing at all, and it is the
argument this subassembly is ultimately judged on. It is developed in
[Aerodynamics](05-aerodynamics.md).

## Where Team 08 sat

The company was divided into subassembly teams. Team 08 owned **joints and
fairings** within the fuselage division:

- every **structural interface** between major assemblies — wings to fuselage,
  empennage to fuselage
- every **aerodynamic fairing** covering those interfaces, plus the nose cone
  and payload ring coverings

This is a structurally awkward position in a project. The joints cannot be
dimensioned until the wing, empennage, pod and avionics teams have fixed their
own geometry, and none of those teams can assemble anything until the joints
exist. Team 08 was last in the design queue and first in the build queue. Most
of the schedule pathology described in
[Project management & risk](08-project-management-and-risk.md) follows directly
from that.

---

## Load cases

Structural checks were run against a **6g gust or manoeuvre case**, multiplied
by the standard aerospace **1.5 safety factor**, giving an effective **9g**
design case:

```
F_design = 9 × F_1g
```

Two consequences worth stating plainly:

- The checks are deliberately conservative. A reserve factor near 2 at 9g is
  not a marginal design.
- The conservatism was doing more work than intended, because several inputs
  (lift distribution, centre of mass) were themselves approximations. See
  [Structural analysis](04-structural-analysis.md) for the assumptions and their
  effect.

---

## Requirements traceability matrix

The requirements below are the ones levied specifically on this subassembly,
traced through to how each was verified and what the outcome was. `RS` refers
to the company requirement specification document.

| ID | Requirement (abridged) | Design response | Verification | Outcome |
|---|---|---|---|---|
| **2.5.1.a** | The wing spars shall be held horizontal without inducing unwanted pitch angles | Fus-MWP joint bored for a friction fit on the aluminium centre bar, tolerance stack computed for the fit | Trial assembly + Graphite Goose | **Met** — no measurable incidence error |
| **2.5.1.b** | HTP main and false rear spars shall be retained | Friction-fit pockets in the Emp-Fus joint, sized with printer allowance | Trial assembly | **Met**, with rework — printed material left in the bore had to be sanded out |
| **2.5.2.a** | 3D printed plastic may act as a joint fitting former but shall not be relied on for significant load transfer; highly loaded formers shall be reinforced with 2014A-T3 sheet straps or bearing plates | Formed 2014A-T3 strap over the Fus-MWP joint to take bolt bearing loads | Ultimate load test | **Partially met** — the strap protected the *upper* joint as intended, but the **lower clamp was left unreinforced and is where the aircraft failed**. See [Test campaign](07-test-campaign.md) |
| **2.6.1.a** | Fairings shall cover the gaps and sharp edges created by the main wing and empennage joints, to avoid flow separation and the drag that follows | Fus-MWP fairing shaped to the NACA 2414 section and extended over the exposed spar; Emp-Fus joint shaped to act as its own fairing | Wind tunnel entry | **Met geometrically**; aerodynamic benefit **not demonstrable** in the tunnel configuration available — see [Aerodynamics](05-aerodynamics.md) |
| **2.6.2.a** | Fairings shall be Styrofoam, plastic moulding or 3D printed plastic | 100% FDM PLA | Material declaration | **Met** — but the choice cost mass; see [Lessons learned](09-lessons-learned.md) |
| **3.2.5.a** | Wing root, wing-to-fuselage, pod-to-fuselage and empennage-to-fuselage joints shall be checked at the critical load case with satisfactory reserve factors for all failure modes | Eight analytical checks at 9g | TB-1 stress report, validated by ultimate load test | **Met for every mode analysed.** The caveat is *"all failure modes"* — shear-out in printed plastic was not among them |
| **3.2.6.a** | A representative "Graphite Goose" assembly shall be loaded to limit under simulated resultant loads, with reactions at the forward fuselage CG and empennage spar positions | Full joint set built and loaded | Graphite Goose test, TB-1 | **Met** — behaved as predicted |

### Reading the matrix honestly

Six of seven requirements were met. The two entries that are not clean passes
are the interesting ones, and they are related:

- **2.5.2.a** was satisfied *in letter* — a 2014A-T3 strap was fitted — but the
  requirement's intent is that *every* highly loaded printed former gets
  reinforcement. The bottom clamp was highly loaded and got none.
- **3.2.5.a** required "all failure modes" to be checked. The failure modes
  enumerated were the classical metallic ones from the taught stress methods:
  bearing, tension, shear, cleavage, prying, bending. None of them describe a
  steel bolt pulling through an anisotropic FDM part.

Both gaps have the same root: the analysis inherited a *material* assumption
from its method. The checks were metal-joint checks, applied to an aircraft
whose critical members were printed plastic.

Extract from the issued requirement specification

*Extract from the issued requirement specification showing the §3.2 structural
verification clauses.*

---

[← Back to overview](../README.md) · [Next: Concept selection →](02-concept-selection.md)

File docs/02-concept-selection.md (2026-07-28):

# 02 · Concept Selection

[← Brief & requirements](01-brief-and-requirements.md) · [Next: Detailed design →](03-detailed-design.md)

---

Fairings were **new to AVDASI 2 in 2024–25**. No previous cohort had built one,
there was no reference geometry, and no guidance existed on what one was even
supposed to look like on this airframe. The starting point was requirement
2.6.1.a and a blank sketch.

That absence of precedent is the reason this section exists. When there is no
obvious answer, the defensible move is to make the selection process explicit
so the choice can be argued about on its merits rather than on taste.

## Step 1 — Establishing criteria

The design and aerodynamics specialists jointly enumerated what the fairing
actually had to do. Seven criteria emerged:

| Criterion | Definition used |
|---|---|
| Cost of materials/processes | Cost of materials for the chosen design |
| Structural integrity | Ability to withstand stresses from the false rear spar and aerodynamic forces |
| Weight | Overall mass of the fairing structure |
| Ease of assembly | Ease of removal and reassembly |
| Aerodynamic performance | Ability to minimise drag and improve airflow |
| Manufacturing complexity | Difficulty of production, tooling, and lab hours required |
| Maintenance requirements | Frequency and ease of maintaining the fairings |

The seven downselection criteria

## Step 2 — Weighting by pairwise comparison

Rather than assigning weights by discussion — which tends to reward whoever
argues hardest — each criterion was compared against every other in a **pairwise
numerical comparison matrix**. The weights fall out of the comparison count
rather than out of an opinion.

Three criteria tied at the top on **21% each**:

- **Aerodynamic performance**
- **Structural integrity**
- **Weight**

This result is worth pausing on, because it is a direct consequence of the
mission. A time-critical outbound leg makes drag matter; a short rural runway
makes mass matter; the false rear spar reaction makes structure matter. The
weighting was not arbitrary — it is the brief, restated as numbers.

It also, in hindsight, contains the seed of the project's clearest failure.
Weight was weighted at 21% and the final fairings came in at **3.1× the mass of
the lightest competing company**. The criterion was correctly identified and
then not enforced. That gap between *knowing* and *doing* is picked up in
[Lessons learned](09-lessons-learned.md).

## Step 3 — Scoring concepts with an MCDA matrix

Concepts were scored against the weighted criteria in a multi-criteria decision
analysis matrix, producing a comparable number per design.

Three rejected preliminary designs

*Three of the preliminary designs that did not make it onto the aircraft.*

### Why each rejected design lost

**Design 2 — rectangular, low surface area.** Cheap to make and light, but the
sharp edges are a separation trigger, which defeats the entire purpose of the
part under 2.6.1.a. It also fouled the payload rings, degrading ease of
assembly. Low surface area is only a virtue if the flow stays attached over it.

**Design 5 — half aerofoil.** Did not extend over the full chord, so it left an
abrupt discontinuity partway along — creating exactly the drag and turbulence it
was meant to remove. Its trailing edges were also thin enough to be a
manufacturing and handling risk.

**Design 4 — full-chord aerofoil outline.** Scored highly and became the basis
of the final part, but needed rework. As drawn it used a rectangular extrude
clamped between the main wing joint and the top clamp — a boltless clamping
mechanism, elegant on paper. It was rejected on **testability**: removing the
fairing between wind tunnel runs with that connection would have been slow and
fiddly, and tunnel time is the scarcest resource in the project.

### From Design 4 to the final part

The delivered fairing kept Design 4's aerofoil planform and changed three
things:

1. An **additional extrude** to cover the exposed length of wing spar
2. A **relocated FRF attachment** to suit where the wing teams had actually cut
   their false rear spars
3. **Bolted** attachment to the fuselage, replacing the clamping mechanism, so
   the part could be taken off and refitted quickly during testing

## What the method was worth

Downselection did what it was supposed to: it made a genuinely novel design
problem tractable and kept the decision objective when there was no precedent to
appeal to. Three honest limitations:

- **It could not model the requirements that had not arrived yet.** The single
  largest source of redesign was other teams changing their interfaces after the
  fact. No amount of concept scoring anticipates that.
- **Even the winning concept was flawed.** It was heavy. Seven criteria in
  tension means every option is a compromise, and the matrix tells you which
  compromise scores best — not that the result is good.
- **Better initial concepts would have come from better guidance.** Concepts
  drawn from scratch with no idea what a fairing is *for* start further from the
  answer than they need to. This is a fair criticism of the exercise as much as
  of the team.

---

[← Brief & requirements](01-brief-and-requirements.md) · [Next: Detailed design →](03-detailed-design.md)

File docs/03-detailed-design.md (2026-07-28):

# 03 · Detailed Design

[← Concept selection](02-concept-selection.md) · [Next: Structural analysis →](04-structural-analysis.md)

---

Ten parts went onto the flying article: five structural, five aerodynamic.

All ten delivered parts

*The delivered part set. Joints and clamps on the left, fairings on the right.*

---

# Part 1 — Joints

The joints exist to attach the wings, HTP and VTP to the **CFRP fuselage spar**
which forms the aircraft's backbone.

## 1.1 Fus-MWP joint (wing to fuselage)

Secures the port and starboard wings to the aluminium centre bar that passes
through the fuselage.

**Fit.** The bore holding the centre bar was sized from a tolerance stack so the
bar would be a **friction fit** — tight enough to satisfy 2.5.1.a (spars held
horizontal, no unwanted pitch angle) without needing a secondary clamping
feature that would add mass and assembly time.

**Anti-rotation.** A cylindrical centre bar has infinite rotational symmetry
and will roll inside its bore. This was solved with a **through-bolt** locking
the bar to the joint. The assessors singled this out as the strongest feature of
the design at Gate 3 — *"good innovation in the centre-spar locating screw."*

It was not free. Drilling the bar reduced the load-bearing section, complicated
manufacture, and — as [Structural analysis](04-structural-analysis.md) argues —
a **cuboid centre bar** would have removed the need for the feature entirely by
being unable to roll in the first place.

**Load path.** PLA is a poor load-bearing material, and 2.5.2.a is explicit
about it. A **formed 2014A-T3 aluminium strap** sits over the joint so that bolt
bearing loads pass through aluminium rather than through printed plastic.

The formed 2014A-T3 aluminium bearing strap

The strap has a known weakness: because it was formed to a shape that does not
perfectly follow the joint's surface, there are **small regions where it does
not contact the joint** and therefore is not carrying load locally. A joint
profile designed for ease of sheet forming would have fixed this at no
aerodynamic cost — the entire joint is hidden under the main fairing, so its
external shape is unconstrained. This was a missed opportunity.

## 1.2 Fus-MWP joint clamps

Two clamps attach the joint to the CFRP fuselage spar via **M4 bolts at 100 mm
spacing**, and are **locally tapered** to follow the spar's own taper and sit
flush.

Clamp thickness was a genuine two-sided compromise: too thin and the clamp fails
in service; too thick and it fouls the payload. 

**Two variants were drawn** because the two test campaigns need different
things:

| Variant | Feature | Reason |
|---|---|---|
| Wind tunnel | 8 mm counterbore | Accepts a flanged bronze bush for the tunnel mounting |
| Structural test | No counterbore | Solid material under the wing nut |

The 8 mm counterbore in the wind tunnel clamp

**This distinction is the single most consequential detail in the project.** The
wind-tunnel clamp was left fitted for the structural test, because disassembling
the pod to swap it would have cost time the team did not have. The counterbore
left a cavity directly under the wing nut, the nut dropped into it, and the bolt
began working through the remaining thin section. The full failure analysis is
in [Test campaign](07-test-campaign.md).

The parts were right. The configuration control was not.

## 1.3 Emp-Fus joint (empennage to fuselage)

Attaches the VTP and HTP to the rear of the fuselage spar — and, unusually, is
**shaped to act as its own fairing**.

That decision is worth defending, because it looks like scope creep and isn't.
By the time flow reaches the empennage it has already crossed the main fairing
and the payload pod, so it is thoroughly disturbed. Adding a *separate* fairing
back there would add wetted area, mass and frontal footprint to smooth flow that
is already turbulent — paying a certain cost for an uncertain benefit.
Aerodynamically shaping the joint itself gets most of the available benefit for
no additional part count.

Exploded view of the empennage joint

**Construction.** Split horizontally into two halves to give access for the VTP
and HTP fittings. The VTP is bonded to the upper half; the HTP main and false
rear spars are friction-fitted per 2.5.1.b.

**Brass inserts.** The two halves are bolted together into **heat-set brass
inserts** melted into the lower half. The original intent was to recess bolt
heads and washers inside the adaptor, but there was not enough internal volume.
Inserts were the fallback.

Honest assessment: it worked here, and it would not always. Heat-setting inserts
locally degrades the PLA around them, and under significant **lateral** load the
inserts could pull free. The structural test applied no lateral loading, so this
was never exercised. The correct fix is to enlarge the joint and return to the
original recessed-bolt scheme — constrained only by the top face, which had to
match the VTP; there was room to grow both taller and wider.

**Cable routing.** Channels were added to the joint to hide the avionics team's
cabling, and the empennage servo housing bonds onto the clamp. Both came from
asking the neighbouring teams what they needed early, and both worked cleanly.

## 1.4 Emp-Fus clamp

Houses the empennage servo, secures the joint, and — like the main wing clamps —
carries a local taper to sit flush against the CFRP spar.

---

# Part 2 — Fairings

Four fairings, all serving requirement 2.6.1.a: cover the gaps and sharp edges
that the joints create, so the flow does not separate over them.

## 2.1 Fus-MWP fairing — the primary part

The largest and most demanding part on the subassembly. It covers the Fus-MWP
joint, its clamps, and **three payload rings**.

The main wing fairing

**Sectional shape.** The fairing adopts the **NACA 2414** profile used by the
port and starboard wing teams, so the covering blends into the wing section it
meets rather than presenting a discontinuity at the join.

**Covering the exposed spar.** With wings fitted and no fairing, roughly
**100 mm of cylindrical wing spar** sits in clean air. Citing Cayley's
minimum-drag shape: in 2D, a circular section produces on the order of **ten
times** the drag of an aerofoil section of the same thickness. Covering that
spar is not a detail — it is most of the justification for the part. The reasoning
is developed in [Aerodynamics](05-aerodynamics.md).

**Structural interface.** A **pinned joint** reacts the small loads from the
false rear spar, with PLA inserts added to stiffen the FRF attachment for the
structural test.

**Testability features**, both driven by the tunnel entry:

- a **vertical split** so the aircraft could be run as a half-model
- a **vertical cutout** clearing the tunnel mounting hardware

The cutout later proved to be an aerodynamic liability — it let flow interfere
between the fairing and the fixtures. A feature added for testability degraded
the very quantity being tested. This is discussed under
[Aerodynamics](05-aerodynamics.md).

Fairing assembly sequence, front
Fairing assembly sequence, rear

*Assembly sequence: two bolts pass from front and rear.*

**Assembly is the part's weakest quality.** Two bolts must pass through holes
set far apart while the fairing is simultaneously held around the fuselage and
over the payload rings. It takes practice. For a part designed to be removed and
refitted repeatedly during a test campaign, that is a real design defect, not a
cosmetic one.

## 2.2 Hemispherical nose cone fairing

Borrowed directly from launch vehicle practice: a **length-to-diameter ratio of
3**, which minimises wetted area for a given diameter while keeping the flow
attached. A worked tolerance stack for this part is in
[Manufacturing & integration](06-manufacturing-and-integration.md).

## 2.3 Front payload ring fairing

The forward payload ring sat well ahead of the main fairing and was exposed. It
was covered with a dedicated shell.

The execution was poor and the team said so: it was attached with **zip ties**
for simplicity, which made it awkward to remove and looked improvised. Making
the covering an integral feature of the ring itself, or using permanent wire
ties, would have been simpler *and* better.

## 2.4 Fuselage shell fairing

Covers the remaining exposed fuselage structure and blends the nose cone into
the main fairing.

---

## Interface control summary

Team 08 held interfaces with **six** other teams. This table is the reason the
subassembly's schedule behaved the way it did.

| Interface | Counterpart | Controlled dimension | Stability |
|---|---|---|---|
| Wing spar → Fus-MWP joint | Port & starboard wing | Spar OD, centre bar length | Stable |
| False rear spar → FRF attachment | Port & starboard wing | FRS position | **Unstable** — the two wing teams chose *different* positions, forcing an asymmetric fairing |
| HTP spars → Emp-Fus joint | Empennage | Spar OD and spacing | Late |
| VTP root → Emp-Fus joint top | Empennage | Root footprint | **Late** — finalised after the Gate 3 design freeze |
| Servo → Emp-Fus clamp | Avionics | Servo envelope, cable route | Late |
| Payload rings → main fairing | Pod | Ring OD, axial position | Changed — a ring moved for CG reasons |

Note the pattern: **every unstable interface is one where the counterpart team
finalised late.** The main wing joint and clamps, whose counterpart geometry was
fixed early, needed almost no rework. The empennage joint, whose counterparts
finalised after design freeze, was revised repeatedly.

The mitigation applied — a **company-wide design freeze**, enforced through the
Design Team Manager role — arrived later than it should have. See
[Project management & risk](08-project-management-and-risk.md).

---

[← Concept selection](02-concept-selection.md) · [Next: Structural analysis →](04-structural-analysis.md)

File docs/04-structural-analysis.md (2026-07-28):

# 04 · Structural Analysis

[← Detailed design](03-detailed-design.md) · [Next: Aerodynamics →](05-aerodynamics.md)

---

## The design case

All checks were run at **6g** (gust or manoeuvre) with the standard aerospace
**1.5** safety factor applied on top:

```
F_design = 6 × 1.5 × F_1g = 9 × F_1g
```

The analysis was completed in **teaching block 1**, deliberately ahead of
detailed design, so that the design team had structural limits to work inside
rather than a structural audit to fail afterwards. That sequencing was correct
and is the main reason the aircraft passed its load test.

## Analysis chain

Each step feeds the next; every step carries an assumption.

**1 · Mass and centre of mass.** A mass table was compiled across all
subassemblies and cross-checked with the other teams, giving

```
CoM = Σ(mᵢzᵢ) / Σmᵢ = 3.69 / 10 = 0.369 m
```

Centre of mass calculation

**2 · Lift.** With the CG located, lift in steady level flight was resolved as a
statics problem to find the force at the main wing joint and around the
empennage joint.

**3 · Wing bending and shear.** The wing spar was modelled as a **cantilever
with uniform lift and weight** across the half-span, giving shear force and
bending moment at the wing root.

**4 · Torsion.** Weight was taken to act **120 mm** from the leading edge and
lift at the **rear of the wing spar**, giving root torsion:

```
T_R = 375 N·mm at 1g  →  3375 N·mm at 9g
```

Wing spar torsion calculation

**5 · Reserve factors.** Root shear, bending and torsion were combined and
carried into the individual joint checks.

## Reserve factors

Reserve factors by check

| Part | Check | RF |
|---|---|---|
| **Centre bar** | **Bending** | **1.95** |
| Spar | Bearing | 2.4 |
| Flange | Prying | 3.4 |
| Spar | Tension | 4.4 |
| Spar | Shear | 5.1 |
| Pin | Shear | 7.4 |
| Spar | Cleavage | 8.9 |
| Lug | Prying | 39.0 |

Data: [`analysis/data/reserve_factors.csv`](../analysis/data/reserve_factors.csv)

**Centre bar sizing.** A **22.2 mm diameter solid bar** gives RF 1.95 — the
lowest value in the set, and therefore the predicted first point of failure.
Retaining it was justified rather than merely accepted: the checks are
conservative by construction (9g, plus simplifying assumptions that all err
toward higher predicted stress), so a reserve factor near 2 on the governing
member is a sound design point, not a marginal one.

**The lug at RF 39 is the other signal in this table.** A reserve factor of 39
is not a triumph, it is 39× more material than the load requires. On a vehicle
where mass drives take-off performance, an outlier that high is an unclaimed
mass saving. It went unclaimed.

---

## Comparing prediction against test

The airframe was loaded to **813 N**, past the ultimate load case.

Load versus deflection

The response is **linear throughout** — no knee, no progressive softening. Least
squares through the origin gives:

| Station | Stiffness |
|---|---|
| Centre | **74 N/mm** |
| Empennage | **102 N/mm** |

Linearity to ultimate load is the strongest single piece of evidence in the
project. It says the structure behaved as a well-understood elastic system right
up to the design case, which is precisely what requirement 3.2.5.a asks for.

> **On this chart's provenance.** The raw acquisition log stayed with the unit,
> so these points are digitised from the original test plot at roughly ±0.1 mm.
> They are more than good enough for a stiffness fit and should not be quoted as
> primary measurements. The original figure is at
> [`figures/structures/load-deflection-original.png`](../figures/structures/load-deflection-original.png)
> and the digitised values, with this caveat in the file header, are in
> [`analysis/data/load_deflection.csv`](../analysis/data/load_deflection.csv).

### Then it failed somewhere else

Past 813 N the measured load fell to 804 N, then abruptly to 764 N. A load drop
without an audible or visible event means something has yielded. The aircraft
was stripped and inspected.

The centre bar — the predicted failure point, RF 1.95 — showed **no deformation
whatsoever**. The failure was **bolt shear-out through the PLA main wing joint
clamp**.

Damage to the main wing joint clamp
Damage to the main wing joint clamp, second view

Full physical narrative in [Test campaign](07-test-campaign.md).

### Why the prediction missed

**No reserve factor was ever computed for any 3D-printed part.** Every check in
the table above is a check on a metallic member — the aluminium centre bar, the
CFRP spar, the aluminium strap and its fasteners. The printed PLA components
were treated, per requirement 2.5.2.a, as non-structural formers. So the
analysis had no term for the mode that actually occurred.

This is not really an arithmetic failure. It is a **scoping** failure, and a
common one in real practice: the analysis boundary was drawn around the parts
the method knew how to handle, and the boundary was never revisited when a
printed part ended up in a primary load path.

Two things follow, and both were true:

- The predictions that *were* made were sound. Linear response to ultimate load
  and an undamaged centre bar confirm the whole analysis chain.
- The predictions did not cover the aircraft. Correct answers to the wrong
  question.

---

## Structural review of the delivered design

### Load path asymmetry — the direct cause

The **upper** half of the Fus-MWP joint is protected: load passes into the
formed 2014A-T3 strap and away from the PLA. The **lower** clamp has no such
protection, and bolt forces bear directly on printed plastic.

The fix is a second bearing plate on the bottom clamp, with three real
objections to weigh:

1. **Mass.** Is this the best use of the budget, when the damage might be
   acceptable and cosmetic?
2. **Space.** The pod and payload ring attachments crowd the region; there may
   not be room.
3. **Complexity.** The clamp assembly is already fiddly. More parts make it
   worse.

The honest resolution is that these forces should have been **modelled** to
settle the question, rather than argued. That modelling was never done — which
is exactly the gap the test found.

### Centre bar: cylindrical versus cuboid

| | Cylindrical (chosen) | Cuboid |
|---|---|---|
| Sizing freedom | Good — matches the round wing spar bore, can sit close to spar OD | Poorer — side length is limited relatively harder |
| Rolling | **Rolls.** Needs a locating bolt, which removes material and complicates manufacture | Cannot roll. No feature needed |
| Second moment of area | Same about every axis; simple | Orientation-dependent; RF calculation more convoluted |

The recommendation is the **cuboid**: it removes a hole from the primary load
path and deletes a manufacturing operation, in exchange for a slightly more
involved calculation. Trading analyst effort for structural simplicity is
usually the right trade.

### Empennage joint

Loads pass predominantly into the CFRP fuselage spar, which is sized for them,
so the unreinforced PLA joint is acceptable at these load cases. Two
observations stand:

- **Brass inserts** could work loose under significant lateral load. The
  structural test applied none, so this remains untested rather than validated.
- **The empennage oscillated noticeably during tunnel running.** Not a failure —
  loads were nowhere near critical — but vibration raises fatigue loading and
  shortens life. Remedies, in increasing order of cost: stiffen the local
  components, add damping, or fit a tuned vibration absorber.

### Mass

Where the subassembly mass went

The subassembly totals **1,011 g**. Of that, **742 g is aerodynamic shell** and
only **269 g carries load**.

The joints are defensible: they are primary structure, and their mass buys
capability. The fairings are not. The company mass report puts all fairings at
**652 g — 11.85% of all-up UAV mass**, and **3.1× the lightest** of the three
companies.

Fairing mass against the other companies

The cause is a single early decision: **commit entirely to FDM PLA**. That
bought fast iteration and the ability to print complex compound curves, both of
which the project genuinely needed given how much the interfaces moved. It cost
mass, and the bill came due at the end.

What makes this a real error rather than an accepted trade is that **some parts
never changed**. The nose cone fairing was stable from early on and could have
been Styrofoam or another light material at no schedule risk. The blanket
material decision was applied to parts that did not need its flexibility.

> **A note on the source data.** The published mass table totals 1,061.5 g. That
> figure includes the M4 × 50 mm bolt line as **56 g**, where the part is 2.8 g
> and quantity 2 — i.e. **5.6 g**, an apparent factor-of-ten transcription slip.
> [`analysis/data/subassembly_mass.csv`](../analysis/data/subassembly_mass.csv)
> carries the corrected value, giving **1,011.1 g**. The difference does not
> change any conclusion, but the corrected number is the one used throughout
> this repository.

---

## Critique of the analytical method

**Conservatism was stacked.** 9g, plus a cantilever model with uniform loading,
plus assumed load application points, all err in the same direction. The result
is a safe design, but one where you cannot easily tell how much of the reserve
is real margin and how much is accumulated pessimism.

**An inconsistent lift value went unnoticed.** The lug cleavage and flange
prying checks — both relating to the aluminium strap — used a lift value
supplied by the wing teams, while every other check used the statics-case lift
derived internally. The discrepancy was found during a final review before the
data repository freeze, too late to investigate properly.

Both values were conservative and the affected reserve factors (3.4 and 39.0)
are far from critical, so no conclusion changes. But *"it didn't matter this
time"* is not the same as *"it was handled"*. The real defect is that two
different values for the same physical quantity coexisted in one stress report
for months without anyone noticing — a review process gap, not an arithmetic
one.

**Test conditions differed between the two campaigns.** In the Graphite Goose
test every part fitted as designed and the structure behaved as predicted. For
the ultimate load test the structure had to be **cable-tied closed**, which
produced uneven deflection between the two wings — Gate 4 flagged exactly this.
An asymmetrically restrained structure does not load its joints the way the
analysis assumed, and this plausibly contributed to the clamp failing when and
where it did.

---

## Recommendations

| Priority | Recommendation | Rationale |
|---|---|---|
| **High** | Compute reserve factors for printed parts in any load path, using measured anisotropic PLA properties | The failure mode that occurred was the one never checked |
| **High** | Add a bearing plate or equivalent to the bottom clamp | Removes the asymmetry that caused the failure |
| **High** | Enforce build-configuration control between test campaigns | The wrong clamp was fitted; the parts themselves were correct |
| Medium | Adopt a cuboid centre bar | Deletes the locating hole and a manufacturing step |
| Medium | Reconcile lift values across all checks before freeze | Two values for one quantity is a review gap |
| Medium | Move stable-geometry fairings to a lighter material | 652 g at 11.85% of UAV mass, 3.1× the best competitor |
| Low | Stiffen or damp the empennage | Oscillation observed in the tunnel; fatigue, not strength |
| Low | Revisit the RF 39 lug | An outlier that large is unclaimed mass |

---

[← Detailed design](03-detailed-design.md) · [Next: Aerodynamics →](05-aerodynamics.md)

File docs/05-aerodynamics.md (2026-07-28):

# 05 · Aerodynamics

[← Structural analysis](04-structural-analysis.md) · [Next: Manufacturing & integration →](06-manufacturing-and-integration.md)

---

Two separate aerodynamic questions were in play, and they had very different
answers available to them:

1. **The wing section.** A well-posed 2D problem with a standard tool (XFoil),
   a standard aerofoil (NACA 2414) and tunnel data to check against.
2. **The fairings.** A 3D problem, brand new to the unit, with no reference
   geometry, no closed-form method, and no usable CFD.

The first is validation work. The second required building an argument from
first principles and then admitting how much the experiment could actually
confirm.

---

# Part 1 — Wing section: prediction versus measurement

## Operating point

Sea level ISA was assumed: ρ = 1.225 kg/m³, μ = 1.789 × 10⁻⁵ Pa·s,
a = 343.54 m/s. At the tunnel speed of 20 m/s:

```
Re = ρVc/μ = (1.225 × 20 × 0.30) / 1.789×10⁻⁵ = 4.11 × 10⁵
M  = V/a   = 20 / 343.54                      = 0.0582
```

Two things follow immediately, and they frame everything below:

- **M = 0.058 — compressibility is irrelevant.** No wave drag term exists at
  this speed. Any drag measured is viscous or form drag.
- **Re = 4.1 × 10⁵ — this is low.** That is squarely in the range where the
  laminar-to-turbulent transition point is sensitive to surface finish and
  freestream turbulence, and where a small Reynolds number error moves
  transition significantly. It is the reason the XFoil and tunnel results were
  never going to coincide.

## Results

XFoil polars were generated at 0° angle of attack for 0° and 30° flap
deflection, and compared against tunnel runs at the same settings.

XFoil versus wind tunnel

| Configuration | Source | C<sub>L,max</sub> | C<sub>D,min</sub> |
|---|---|---|---|
| Clean, 0° flap | XFoil | 1.25 | ~0.007 |
| Clean, 0° flap | Tunnel | **1.00** | **0.030** |
| Flap 30° | XFoil | 1.80 | 0.070 |
| Flap 30° | Tunnel | **1.25** | **0.200** |

Original polars: [XFoil clean](../figures/aero/drag-polar-xfoil-clean.png) ·
[XFoil 30° flap](../figures/aero/drag-polar-xfoil-flap30.png) ·
[tunnel clean](../figures/aero/drag-polar-tunnel-clean.png) ·
[tunnel 30° flap](../figures/aero/drag-polar-tunnel-flap30.png)

The pattern is consistent and in the expected direction: **the tunnel loses lift
and gains drag in both configurations.** The theoretical curves are smoother,
reach higher peak lift, and sit at lower drag for a given lift. The experimental
curves are more rounded — flow separation begins earlier and viscous losses are
higher.

Deploying the flap to 30° increases camber, raising both C<sub>L</sub> and
effective angle of attack. The prediction says peak lift rises to 1.80 at the
cost of drag climbing from 0.07 to 0.15. The tunnel agrees on the *shape* of
that trade and disagrees on its magnitude: peak lift only reaches 1.25, and drag
starts at 0.20 — already above where XFoil's flapped polar ends.

## Why they differ

Four mechanisms, roughly in order of contribution:

**1 · Finite span.** XFoil solves a 2D section of infinite span. The tunnel
model has ends. Tip vortices generate induced drag and shed bound circulation,
which cuts lift and adds drag — a term entirely absent from the 2D solution.
This is the dominant effect and it acts in exactly the direction observed.

**2 · Wall interference.** Tunnel walls constrict the flow around the model,
locally accelerating it and altering the pressure distribution the model sees.
The measured coefficients are therefore not free-air coefficients.

**3 · Reynolds number mismatch.** The true Re depends on the actual chord,
surface condition and freestream turbulence intensity, none of which match the
idealised value fed to XFoil. At Re ≈ 4 × 10⁵ even a modest mismatch shifts
transition, and transition location sets both separation onset and skin friction.

**4 · Surface finish.** The models are not the smooth analytical surface XFoil
assumes.

**The conclusion is not that XFoil was wrong.** It answered its own question
correctly. It is that a 2D, inviscid-plus-boundary-layer, infinite-span,
smooth-surface model is a *lower bound on drag and an upper bound on lift*, and
should be read as such rather than as a prediction of what a real finite wing in
a real tunnel will do.

---

# Part 2 — Fairings

## Working without a tool

Fairings were new to AVDASI 2 this year. There was no prior geometry to
reference and no closed-form method for the drag benefit of an arbitrary 3D
fairing. CFD was considered and rejected — honestly — on two grounds: the team
lacked the technical depth to set up and validate a credible model, and the
readily available packages do not give trustworthy results at this scale without
that depth. A CFD result nobody can defend is worse than no CFD result.

So the design was argued from drag decomposition instead.

## The argument

**Step 1 — establish the objective.** The mission requires the UAV to fly to the
test centre as fast as possible. Not furthest, not longest. **Minimising total
drag is therefore the fairings' entire purpose**, and every shaping decision
follows from that one sentence.

**Step 2 — decompose the drag.** Total drag splits into normal pressure drag and
skin friction drag. At 20 m/s, with M = 0.058:

- **Wave drag: zero.** Not transonic.
- **Induced drag:** a wing term, not a fuselage-fairing term.
- **Normal pressure drag: negligible at this speed.**
- **Which leaves form drag and skin friction drag** as the only levers.

**Step 3 — recognise the trade.** Low skin friction drag and low form drag pull
in opposite directions. A fairing *adds wetted area*, which adds skin friction —
so it can only be worth fitting if it removes more form drag than the friction it
introduces. This is the central design tension of the whole part, and it is why
"just cover everything" is not automatically right.

**Step 4 — find where form drag is worst.** The exposed items are the payload
rings, the main wing joint, and roughly **100 mm of cylindrical wing spar**.
Using Cayley's minimum-drag shape (1810): in 2D, a circular section produces on
the order of **ten times** the drag of an aerofoil section of the same
thickness. A bluff cylinder in clean air is about the worst thing that can be
left on an aircraft.

**Step 5 — shape accordingly.** The fairing takes the **NACA 2414** section used
by the wing teams, so the covering is continuous with the wing it meets. It
maintains laminar flow as far aft as possible, thins the boundary layer, and
minimises abrupt contour changes.

The empennage joint was shaped as its own fairing on the same reasoning, argued
in [Detailed design](03-detailed-design.md).

## What the tunnel actually showed

Fuselage drag with fairings fitted

Averaged over the campaign, **fairings-on recorded 0.09 N more drag than
fairings-off.**

Before interpreting that: seven repeat runs at 0° give a run-to-run standard
deviation of **σ = 0.34 N**. The measured difference is roughly a quarter of one
standard deviation of the measurement noise. **It is not a resolvable
difference.** The correct statement is that the tunnel could not detect any
effect, in either direction — and indeed at some 0° trials, fairings-on recorded
*lower* drag than fairings-off.

Data: [`analysis/data/tunnel_runs_fairings_on.csv`](../analysis/data/tunnel_runs_fairings_on.csv)

### Four reasons the test could not answer the question

**1 · The wings were not fitted.** The tunnel could only accommodate the
fuselage. This removes the single largest justification for the fairing — the
100 mm of exposed spar — from the experiment entirely. The main benefit was
untestable in the available facility, while the fairing's cost (extra wetted
area) was fully present. **The test was structurally biased against the part.**

**2 · Open sides.** With no wings attached, the fairing's flanks were open. Flow
crept inside and raised drag substantially — a condition that cannot occur on the
assembled aircraft.

The fairing in the tunnel showing the vertical cutout

**3 · The vertical cutout.** Added so the fairing would clear the tunnel
mounting hardware, it let flow interfere between the fairing and the fixtures.
A feature added purely for testability degraded the quantity being tested.

Exposed spar section in the tunnel

**4 · The pod dominated.** The payload pod and rings are physically large and
were by far the biggest drag source present. Whatever the fairing contributed
was buried under a much larger signal.

There is also a **blockage** effect: the fairing increases the model's frontal
area relative to the test section, and with wall interference already
constricting the flow, this shifts the measured pressure distribution.

### The honest conclusion

**Experimentally: inconclusive.** The measured difference is inside the noise,
and the configuration prevented the primary benefit from appearing at all.

**Theoretically: the fairing should reduce drag in real operation.** The
argument does not depend on the tunnel. Covering a bluff cylinder with an
aerofoil section removes form drag that is present in flight regardless of what
a fuselage-only tunnel model can measure. That drag reduction, and the fact that
the measured skin friction penalty was too small to detect, is the actual
result: **a large form-drag benefit was traded for a friction penalty that
proved unmeasurable.**

What would be needed to close this properly is a test with wings fitted, or
validated CFD. Neither was available.

## Mass, and an argument that does not survive

The fairings account for **11.85% of all-up UAV mass**.

There is a superficially appealing counter-argument: the aircraft has no
propulsion in test, so as a pure glider a heavier airframe flies *faster* for
the same L/D — the reason competition sailplanes carry water ballast.

That argument does not survive contact with the mission. The UAV is not a
glider. Every gram of fairing is a gram of thrust not spent carrying blood
samples, and take-off is limited by a short rural runway. **Lighter is
unambiguously better here.** The ballast analogy is a real effect applied to the
wrong vehicle.

Better options existed: formed aluminium sheet, or foam in selected areas —
foam carrying its own penalty of moisture sensitivity in real weather.

## Design defects worth recording

- **The tunnel fixture has no counterbore.** Bolt heads and nuts sit proud in
  the airflow. On a real vehicle that is both a drag source and a hazard. It
  should have been counterbored; it was not.
- **Surface finish.** FDM leaves a rough outer surface, made worse in places by
  post-processing. At Re ≈ 4 × 10⁵ surface roughness moves transition — so the
  manufacturing method partly undermined the laminar-flow intent of the shape.
- **Blunt profile at the wing root.** Gate 3 judged the main fairing profile
  *"very simplistic and… non-optimum for aerodynamics"*. Fair. Earlier access to
  a complete CAD assembly would have allowed a slimmer, better-integrated shape,
  and smaller payload rings would have let the whole fairing sit lower.

---

[← Structural analysis](04-structural-analysis.md) · [Next: Manufacturing & integration →](06-manufacturing-and-integration.md)

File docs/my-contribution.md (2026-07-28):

# My Contribution

**Jad El Badaoui** — MEng Aerospace Engineering, University of Bristol

[← Lessons learned](09-lessons-learned.md) · [Back to overview](../README.md)

---

I held **four roles** on this project. That was a deliberate choice rather than
an accident of allocation: I wanted to find out which parts of engineering I was
actually good at, and the only way to do that was to take on more than one and
find out by doing.

| Role | Scope |
|---|---|
| **Fuselage Division Design Team Manager** | Cross-team design authority across the whole fuselage division |
| **Project Manager, Team 08** | Planning, scheduling, and inter-divisional coordination |
| **Aero Specialist** | Aerodynamic design rationale and wind tunnel analysis |
| **Design Specialist** | CAD design of joints and fairings |

In the team's technical report I authored the **Project Management** section in
full, the **Aerodynamics** section in full, and the **Design and Manufacturing**
downselection and subassembly design sections (3.1–3.2).

---

## Design Team Manager — fuselage division

The DTM role sits above individual teams and owns design coherence across a
division. In practice this meant three things.

**Enforcing a design freeze.** Several teams — VTP in particular — were still
finalising geometry after Gate 3, which meant Team 08 was continually redesigning
interfaces to parts that were supposed to be settled. I imposed a company-wide
design freeze to stop it. It was the right mechanism, and my clear judgement in
hindsight is that I applied it too late: most of the rework it was designed to
prevent had already happened. → [Lessons learned §6](09-lessons-learned.md)

**Building divisional network diagrams.** Working with the other DTMs, I
produced network diagrams at *divisional* level, capturing dependencies and
critical paths across teams rather than within them. These were the documents
that connected team objectives to company objectives, and they were the layer
that had otherwise been missing entirely.

Company fuselage division network diagram

**Hands-on manufacturing and build.** The DTM role carried an expectation of
being in the lab. I took it up deliberately — engineers in industry need
hands-on prototype experience, and it is the fastest way to learn what a design
actually costs to make. Printing, post-processing, fitting brass inserts and
trial assembly all sat within this.

---

## Project Manager

I built and maintained the three planning documents that governed Team 08's
year, and I made them **congruent** with one another — a WBS, a Gantt and a
network diagram are three views of one project, and if they disagree, the team
stops trusting all three.

Design and build phase Gantt

The change I would point to as most effective was in the design and build phase
(weeks 7–17): breaking work down to a genuinely feasible task granularity,
building in explicit slack, and **assigning each task to a named individual**
rather than to the team. Accountability at the level of a person rather than a
group changed how the plan was used.

I also introduced a **mandatory 5–10 minute reflection after every meeting**.
This came from a team self-assessment against Lencioni's five dysfunctions model
partway through teaching block 1, which showed our weakest areas were
commitment (3.00) and attention to results (3.13) — and which matched our
performance at the preliminary design review, where we were not confident in our
own designs and calculations. Alongside closer follow-up and specific individual
accountability before each milestone, the second self-assessment in teaching
block 2 showed a marked improvement.

**The honest assessment of my planning work** is in
[Project management & risk](08-project-management-and-risk.md): my critical path
predicted 48 hours and the team clocked 105. The estimates were not the problem
— the model was. I planned the dependencies inside my team and not the ones I
did not control, which for a team sitting downstream of six others were the only
ones that mattered.

---

## Aero Specialist

I owned the aerodynamic argument for the fairings and the wing section analysis,
and I attended the wind tunnel test.

I joined this specialism expecting to learn new equations and CFD. Neither was
available — there was no closed-form method for the drag benefit of an arbitrary
3D fairing, and CFD at the fidelity needed was beyond what the team could set up
and defend. A CFD result nobody can justify is worse than none.

So the work became something harder and more useful: **building an argument from
drag decomposition**. Establishing that at M = 0.058 wave and normal pressure
drag are negligible, so form and skin friction drag are the only levers;
recognising that a fairing necessarily *adds* wetted area and can only pay for
itself by removing more form drag than the friction it introduces; identifying
the exposed cylindrical wing spar as the dominant form-drag source via Cayley's
minimum-drag shape; and shaping the fairing to the NACA 2414 section accordingly.

I also did the XFoil-versus-tunnel comparison for the port wing and worked
through why they disagree — finite span, wall interference, Reynolds mismatch,
surface finish.

The result I am most willing to defend is the one that says **the experiment
could not answer the question**. The measured fairings-on penalty was 0.09 N
against a run-to-run scatter of 0.34 N, and the test configuration — fuselage
only, no wings — removed the fairing's primary benefit while leaving its cost
fully present. Reporting that as inconclusive, rather than dressing it up in
either direction, is the correct engineering answer.
→ [Aerodynamics](05-aerodynamics.md)

---

## Design Specialist

CAD design of the joints and fairings in Autodesk Inventor, including the
downselection process and subassembly design that I wrote up in the technical
report.

This is where the project pushed me hardest, because fairings were **new to the
unit that year**. There was no reference geometry and no guidance on what one is
even supposed to look like on this airframe — just a requirement and a blank
sketch. Making that tractable meant building the selection process explicitly:
seven criteria, weighted by pairwise comparison so the weights came out of the
comparison rather than out of whoever argued hardest, then scored in an MCDA
matrix. → [Concept selection](02-concept-selection.md)

I also designed the **spar plugs** for the wing attachment, which went through
the starboard wing PM for approval — a clean example of the design cycle working
as intended.

### Taking over the company CAD assembly

The company's Technical Director was responsible for assembling the entire UAV
in CAD and did not complete it. With the data repository deadline approaching,
my design team stepped outside our remit and **assembled the whole aircraft for
the company**.

That model is what is published in [`cad/`](../cad/), and it is the reason other
teams' subassemblies appear in this repository at all. Of everything I did this
year it is the piece I am most pleased with — not for the CAD, which was
laborious rather than difficult, but because a small team chose to absorb
someone else's failure rather than let the company miss its deadline.

---

## What I learned about how I work

A structured self-evaluation, cross-checked against how my teammates rated me,
identified me as a **shaper** in the Belbin model. That reading was accurate and
it cuts both ways.

The upside is real: I brought energy and drive at points where the project
needed it, and I was willing to take on work outside my remit — the design
freeze, the divisional diagrams, the company CAD assembly — rather than watch
things fail.

The downside is equally real, and I would rather record it than hide it. A
competitive, low-tolerance-for-error approach led me to **give instructions
rather than assign responsibility**, and that created friction. I eventually
understood that I was addressing the problem the wrong way: each teammate worked
differently, and my communication should have adapted to the person rather than
expecting the person to adapt to me. Handled better, it would have produced a
more collaborative and inclusive team rather than a more compliant one.

That is the single most useful thing this project taught me, and it is not a
technical lesson.

---

## Where this took me

Working across four roles made me a more rounded engineer than any one of them
would have — technically, administratively, and in leading people. It also
settled a question I had been circling: I want to work in aerospace, and I want
to get to a **technical director** position, where the job is combining deep
technical knowledge with everything the other specialisms do.

The moment that settled it was not a calculation. It was my design team stepping
up to take over the full CAD assembly when someone else had fallen behind, and
delivering it — because we had built the kind of working environment where that
was possible.

---

[← Lessons learned](09-lessons-learned.md) · [Back to overview](../README.md)

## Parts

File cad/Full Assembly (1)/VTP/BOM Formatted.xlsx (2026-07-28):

AVDASI2 Bill of Materials |  |  |  |  | Issue number | 02
 |  |  |  |  | Issue date | 2025-01-14
 | BOM number: BOM-0006 |  |  |  | Company: | Albatross Aviation (Company A)
 | BOM title: VTP and Rudder Assembly |  |  |  | Group/Division: | Team 05
Item Ref | Part number |  |  | Title | Nº of | Description/Notes
1 | 1000-1 |  |  | Assembly - VTP and Rudder | 1
2 |  | - | 1001-1 | Assembly - VTP Body | 1
3 |  | - | 1001-10 | Main Spar - VTP | 1 | ØOD 7, 2.5mm thick
4 |  | - | 1001-11 | False Rear Spar - VTP | 1 | ØOD 3, 1mm thick; Also included in Rudder Assy
5 |  | - | 1001-12 | Rib 1 [Top] - VTP | 1 | 3mm thick
6 |  | - | 1001-13 | Rib 2 [Second] - VTP | 1 | (as item 5)
7 |  | - | 1001-14 | Rib 3 [Middle] - VTP | 1 | (as item 5)
8 |  | - | 1001-15 | Rib 4 [Bottom] - VTP | 1 | (as item 5)
9 |  | - | 1001-16 | Skin - VTP | 1 | 60000mm2 sheet
10 |  | - | 1001-17 | Top Aerofoil Foam Half-Section 1 - VTP | 1
11 |  | - | 1001-18 | Top Aerofoil Foam Half-Section 2 - VTP | 1
12 |  | - | 1001-19 | Middle Aerofoil Foam Half-Section 1 - VTP | 1
13 |  | - | 1001-20 | Middle Aerofoil Foam Half-Section 2 - VTP | 1
14 |  | - | 1001-21 | Bottom Aerofoil Foam Half-Section 1 - VTP | 1
15 |  | - | 1001-22 | Bottom Aerofoil Foam Half-Section 2 - VTP | 1
16 |  | - | 1001-23 | Servo Front Retaining Rod | 1 | Ø2
17 |  | - | 1001-24 | Servo Rear Retaining Rod | 1 | Ø2
18 |  | - | 1002-1 | Assembly - Rudder | 1
19 |  | - | 1002-10 | Aerofoil Foam Half-Section 1 - Rudder | 1
20 |  | - | 1002-11 | Aerofoil Foam Half-Section 2 - Rudder | 1
21 |  | - | 1002-12 | Skin - Rudder | 1 | 15000mm2 sheet
22 |  | - | 1002-13 | Rudder Top Rib | 1 | 3mm thick
23 |  | - | 1002-14 | Rudder Bottom Rib | 1 | 3mm thick
24 |  | - | 1003-1 | Assembly- Linkage and Actuator | 1
25 |  | - | 1003-10 | Servo Motor - EMAX ES09MD | 1
26 |  | - | 1003-11 | Control Horn | 1 | Also included in Rudder Assy
27 |  | - | 1003-12 | Actuator Rod | 1 | Ø1
28 |  | - | 1003-13 | Servo Arm | 1
29 |  | - | 1003-14 | M2x16 Bolt | 2 | Also included in Rudder Assy
30 |  | - | 1003-15 | M2 Nut | 2 | Also included in Rudder Assy
31 |  | - | 1003-16 | M2 Washer | 4 | Also included in Rudder Assy
32 |  | - | 1003-17 | Control Horn Backplate | 1 | Also included in Rudder Assy

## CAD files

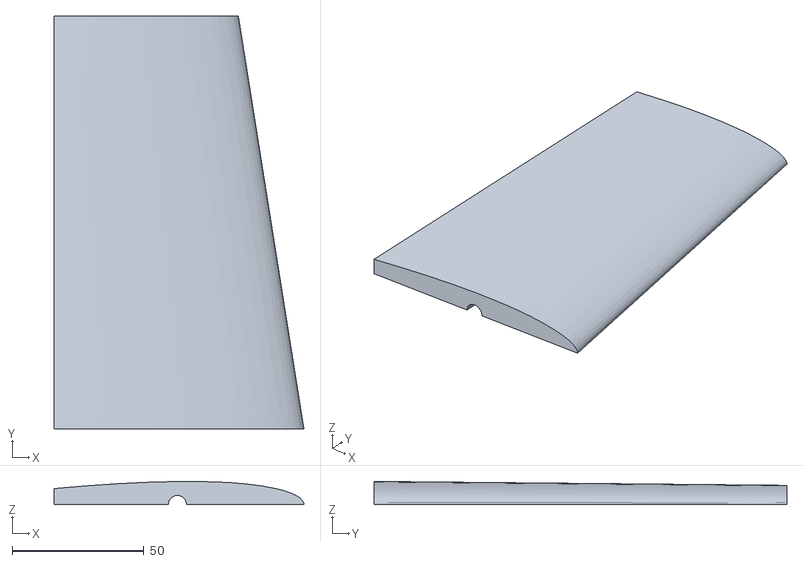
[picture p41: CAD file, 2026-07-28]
cad/Full Assembly (1)/VTP/5P.00.10.01-IB-VTP-Body-Final-Right-Main-WITHOUT-HOLES.stl
95.0 x 157.0 x 8.81

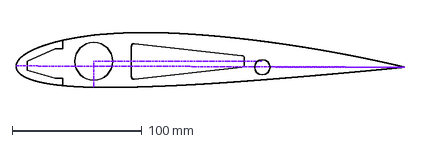
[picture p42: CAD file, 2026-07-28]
cad/Full Assembly (1)/S Wing/2) Ribs/laser cutter docs/rib 12.dxf
300.0 x 42.4 mm

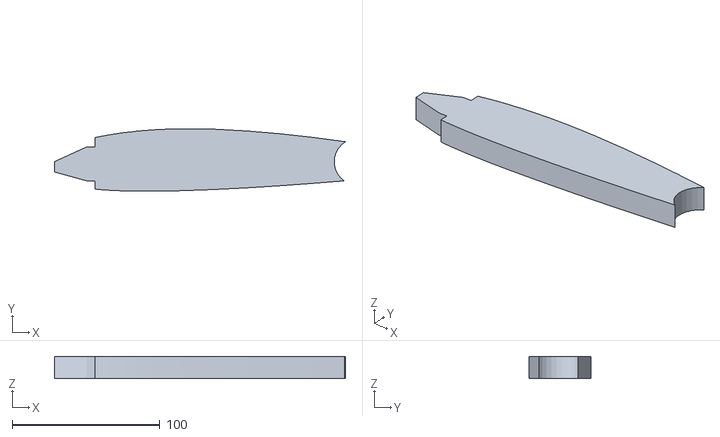
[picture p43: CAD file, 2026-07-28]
cad/Full Assembly (1)/S Wing/2) Ribs/stl files/Aileron Foam Cut.stl
197.3 x 42.4 x 15.0

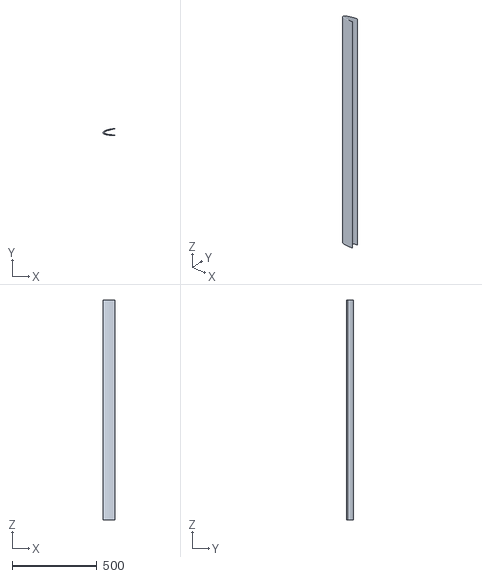
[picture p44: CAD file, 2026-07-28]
cad/Full Assembly (1)/S Wing/3) Leading edge/stl files/3P.04.JS.2414 rib leading edge inner.stl
72.9 x 41.5 x 1300.0

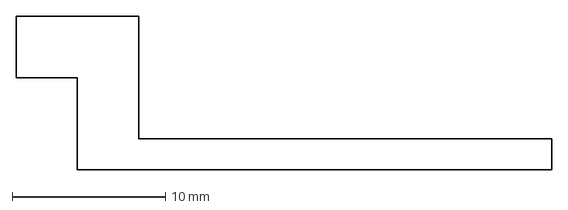
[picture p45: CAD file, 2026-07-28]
cad/Full Assembly (1)/S Wing/Avionics Cradle/Avionics Cradle Sketch 1.dxf
35.0 x 10.0 mm

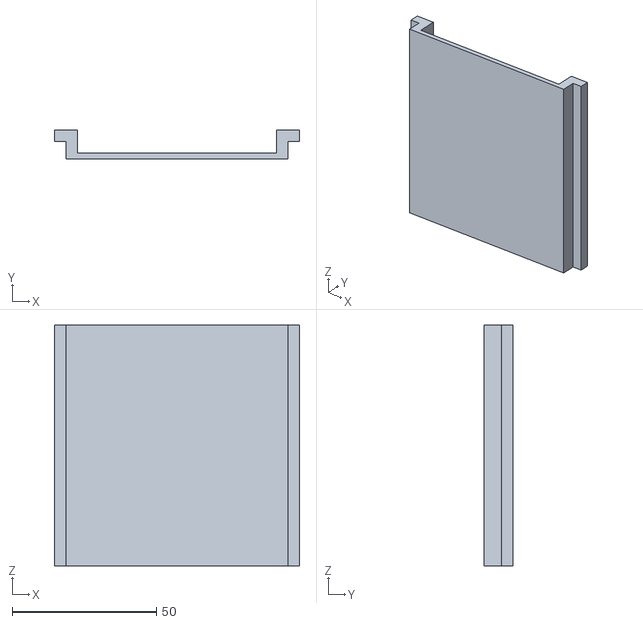
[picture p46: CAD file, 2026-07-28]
cad/Full Assembly (1)/S Wing/Avionics Cradle/STL CRADLE/Avionics Cradle (11-12).stl
85.0 x 10.0 x 83.5

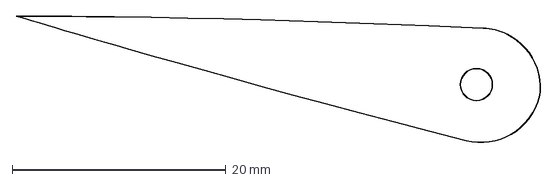
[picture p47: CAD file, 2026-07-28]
cad/Full Assembly (1)/VTP/rudderBottom.dxf
49.0 x 11.9 mm

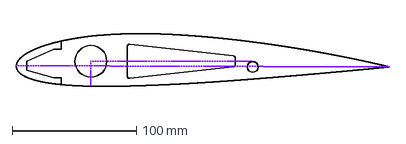
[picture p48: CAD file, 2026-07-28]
cad/Full Assembly (1)/S Wing/2) Ribs/laser cutter docs/rib 7.dxf
300.0 x 42.4 mm

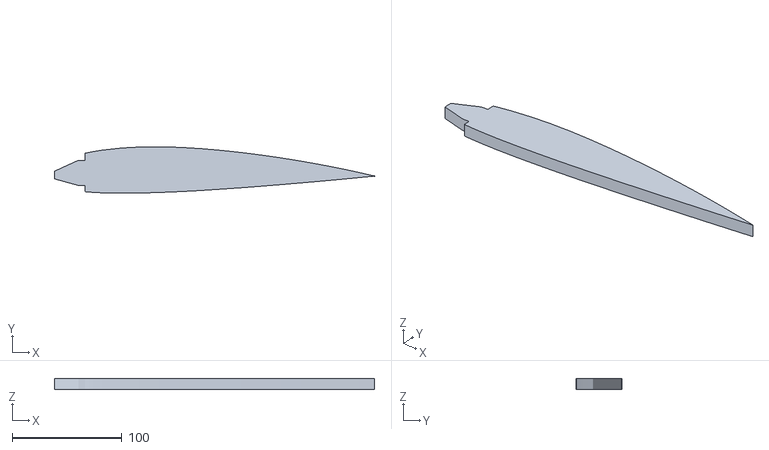
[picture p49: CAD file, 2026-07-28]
cad/Full Assembly (1)/S Wing/2) Ribs/stl files/3P.02.JS.root rib template foam.stl
291.6 x 42.3 x 10.0

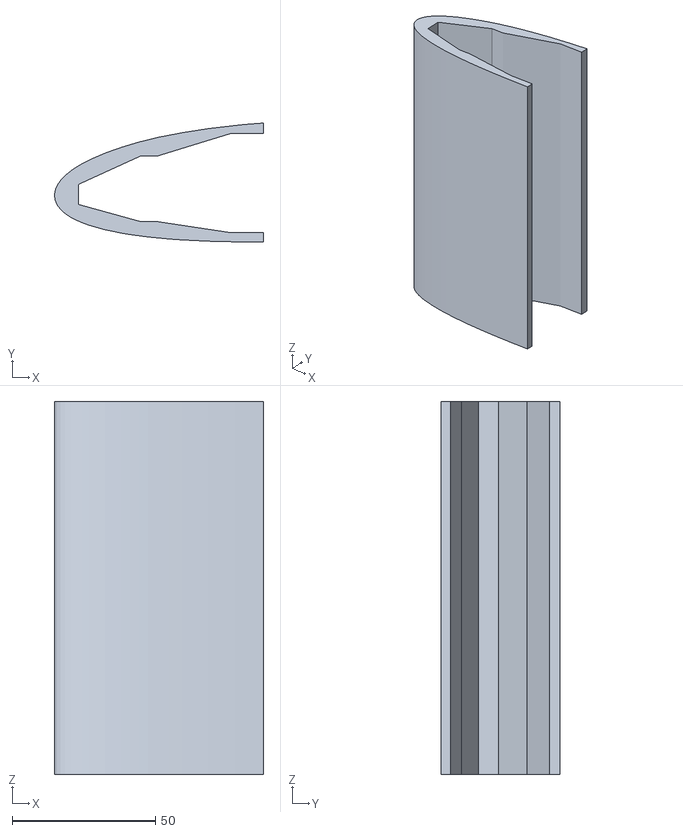
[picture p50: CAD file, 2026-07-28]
cad/Full Assembly (1)/S Wing/3) Leading edge/stl files/3P.04.JS.2414 rib leading edge inner short.stl
72.9 x 41.5 x 130.0

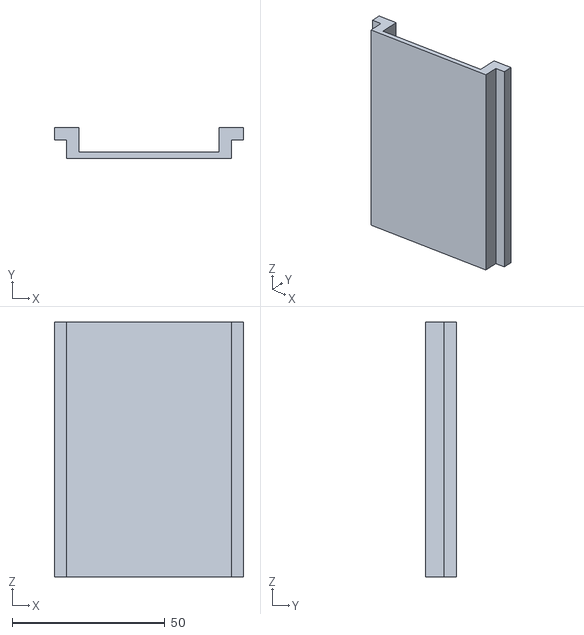
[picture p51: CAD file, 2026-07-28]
cad/Full Assembly (1)/S Wing/Avionics Cradle/STL CRADLE/Avionics Cradle (12-13).stl
62.0 x 10.0 x 83.5

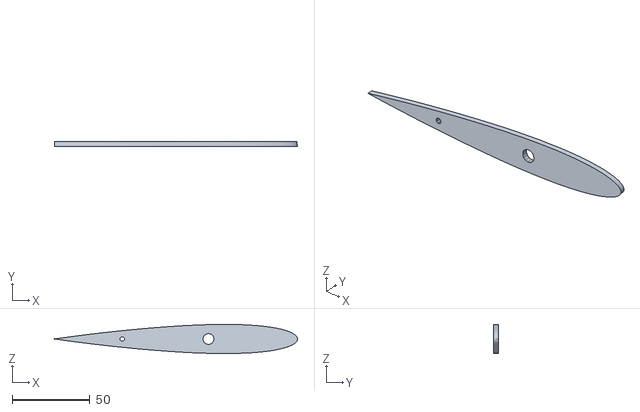
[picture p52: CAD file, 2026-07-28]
cad/Full Assembly (1)/VTP/thirdRib.stl
156.0 x 3.00 x 18.7

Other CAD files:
cad/Full Assembly (1)/VTP/Drawings/5D.01.02.01-IB-VTP-Body-Final-Left-Main.dwg
cad/Full Assembly (1)/VTP/Drawings/5D.01.11.01-IB-VTP-Body-Final-Right-Main.dwg
cad/Full Assembly (1)/VTP/Drawings/5D.01.12.01-IB-VTP-Body-Master-Assy.dwg
cad/Full Assembly (1)/VTP/Drawings/5D.01.09.01-IB-VTP-Rudder-Master-Assy.dwg
cad/Full Assembly (1)/VTP/5P.00.10.01-IB-VTP-Body-Final-left-Main-WITHOUT-HOLES.stl
cad/Full Assembly (1)/VTP/Drawings/5P.00.01.01-IB-VTP-Rudder.dwg
cad/Full Assembly (1)/HTP&elevator/6A-002.iam
cad/Full Assembly (1)/HTP&elevator/6P-001.ipt
cad/Full Assembly (1)/HTP&elevator/6P-002.ipt
cad/Full Assembly (1)/HTP&elevator/6P-003.ipt
cad/Full Assembly (1)/HTP&elevator/6P-004.ipt
cad/Full Assembly (1)/HTP&elevator/6P-005.ipt
cad/Full Assembly (1)/HTP&elevator/6P-006.ipt
cad/Full Assembly (1)/HTP&elevator/6P-007.ipt
cad/Full Assembly (1)/HTP&elevator/6P-008.ipt
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

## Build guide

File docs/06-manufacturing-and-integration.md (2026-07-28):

# 06 · Manufacturing and Integration

[← Aerodynamics](05-aerodynamics.md) · [Next: Test campaign →](07-test-campaign.md)

---

## The decision that shaped everything: 100% additive

Every flight part was **FDM printed in PLA**. This was decided early, on the
back of experience gained printing the main wing joint and empennage for the
Graphite Goose prototype, and it was defensible at the time:

- **Fast iteration** — essential given how much neighbouring geometry moved
- **Near-zero attended build time** — prints run overnight without a person
  present, which matters when lab hours are a hard budget
- **Complex compound curves** — the fairing shapes are difficult by any other
  available process

It cost mass and it cost strength, and by the time that was clear it was too
late to change. The full accounting is in
[Structural analysis](04-structural-analysis.md) and
[Lessons learned](09-lessons-learned.md).

The specific defect is not choosing additive manufacture — it is choosing it
**for everything, permanently, without revisiting**. Parts that never changed,
like the nose cone fairing, carried the mass penalty of a flexibility they never
used.

---

## Tolerance analysis

The first prints made something obvious: **CAD nominal dimensions do not survive
contact with a printer.** A tolerance stack was therefore run for every part
before printing.

Worked example, hemispherical nose cone fairing:

| Question | Answer (mm) |
|---|---|
| Achievable tolerance on the fairing shaft diameter? | 3D printers hold **±0.5 mm** on diameter |
| Target clearance? | **0.2 mm** minimum for compatibility |
| Minimum fuselage inner diameter (from manufacturer)? | 36.0 − 0.1 = **35.9** |
| Maximum permissible shaft size? | 35.9 − 0.2 = **35.7** |
| Nominal shaft size? | 35.7 − 0.5 = **35.2** |

The logic runs from the worst-case mating dimension inward, subtracting the
required clearance and then the process capability. Both uncertainties are
stacked — the printer's and the CFRP supplier's — rather than assuming either is
nominal.

This is straightforward, it was done consistently, and it is the reason parts
generally fitted first time. It is one of the quieter successes of the project.

---

## Process notes, part by part

### Main wing fairing — printed in four pieces

Too large for the print bed, so it was split into **four segments and bonded**.
The bonding came out well. Two problems did not:

- The printer **erred on one edge**, leaving a gap that had to be filled with a
  bonded balsa insert. Functional, visibly a repair.
- **Bolts and nuts were left exposed.** Brass inserts should have been used
  here too — the part carries no significant load, so there was no reason not
  to.

### Empennage joint — the best-executed part

- **Brass inserts** heat-set neatly, holding a flush fit between the halves
- **Servo housing** bonded cleanly onto the clamp
- **Avionics cabling** routed through channels designed into the joint

The one genuine problem was the **HTP spar bore**. FDM left support material
inside it which had to be sanded out; the sanding was untidy enough that during
the structural test the rough bore was **mistaken for a structural failure**.

The lesson is specific and useful: a larger designed-in allowance would have
avoided it, but predicting how much material a printer will leave in a blind
bore is genuinely unreliable. Where it matters, design the feature so it can be
reamed to size rather than hoping the print is clean.

### Front payload ring cover — the weakest execution

Attached with **zip ties**. Simple, inelegant, and awkward to remove. The team's
own assessment stands: making the cover integral to the ring, or using permanent
wire ties, would have been simpler *and* better. This is what a rushed solution
to a late-emerging problem looks like.

---

## Integration — the strongest area

> *"As a result of us compromising so much with other teams, integration became
> our strongest point."*

Every interface was reviewed repeatedly for fit, shape, tolerance and position
against the other teams' existing plans. Being downstream of six teams forced a
discipline of asking rather than assuming, and it paid off: the assembled
aircraft went together.

Trial assembly of the airframe

### The one interface that failed

The **false rear spar joint**. The wing teams cut their false rear spars before
Team 08 established the interface, and — worse — **the two wing teams chose
different FRS positions**, forcing an asymmetric fairing and a longer design
cycle.

It then failed twice over on the day. The team member present at the structural
test was **the only one who had not attended the practice assembly**, so when
the FRF attachment did not go together, a makeshift solution was improvised and
the joint was discarded entirely. Gate 4 recorded the consequence: *"cable ties
required to close structures."*

Two independent causes, both organisational:

1. **A late interface** — not asking the wing teams before they cut
2. **Lost build knowledge** — the practice assembly did not transfer to the
   person who needed it

Neither is a CAD problem. The parts were compatible: on 3 March a trial assembly
verified that the FRF attachments aligned correctly with their respective wing
spars. The knowledge of *how* to assemble them was what went missing.

---

## The CAD rebuild

Halfway through the year the model was rebuilt from scratch.

**Why.** The original assemblies were constructed by importing other teams'
parts directly and then adjusting around them. Inventor's referencing system
then propagated every upstream change into Team 08's parts — and upstream
changed constantly. The team's own description was *"Frankenstein's monster CAD
files"*: a model that could no longer be developed because its own history was
controlled by six other people.

**The fix.** Parts were redrawn against **sketches derived from** other teams'
CAD, rather than referencing their geometry live. This decouples the model: an
upstream change now requires a deliberate update to a sketch instead of silently
rippling through.

**The result.** The design process became significantly more streamlined
afterwards. Alongside it the team recorded a candid list of CAD skills actually
learned: constraining measurements, tolerancing, and — disarmingly —
using a mouse properly.

Rebuilding a model mid-project is expensive and feels like lost ground. It was
the right call, and the residue of the old approach is still visible in the raw
folder structure: a duplicated `JointsAndFairinsg` tree nested three levels
deep, removed before publishing (see [`cad/README.md`](../cad/README.md)).

### The wider integration story

The company's Technical Director was responsible for assembling the full UAV in
CAD and did not complete it. With the repository deadline approaching, **Team
08's design specialists took over and assembled the entire aircraft** — outside
their remit, for the whole company.

That assembly is the model published in [`cad/`](../cad/), and it is why other
teams' subassemblies appear in this repository at all.

---

[← Aerodynamics](05-aerodynamics.md) · [Next: Test campaign →](07-test-campaign.md)

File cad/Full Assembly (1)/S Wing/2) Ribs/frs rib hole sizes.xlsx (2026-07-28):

rib num | frs length max | frs length min | main spar length max | length min | length avg | diameter
13 | 120 | 143 | 100 | 123 | 131.5 | 12.428125
12 | 208.5 | 231.5 | 188.5 | 211.5 | 220 | 11.875
11 | 297 | 320 | 277 | 300 | 308.5 | 11.321875
10 | 394.75 | 417.75 | 374.75 | 397.75 | 406.25 | 10.7109375
9 | 508.5 | 531.5 | 488.5 | 511.5 | 520 | 10
8 | 622.25 | 645.25 | 602.25 | 625.25 | 633.75 | 9.2890625
7 | 720 | 743 | 700 | 723 | 731.5 | 8.678125
6 | 808.5 | 831.5 | 788.5 | 811.5 | 820 | 8.125
5 | 897 | 920 | 877 | 900 | 908.5 | 7.571875
4 | 1004.667 | 1027.667 | 984.667 | 1007.667 | 1016.167 | 6.89895625
3 | 1112.334 | 1135.334 | 1092.334 | 1115.334 | 1123.834 | 6.2260375
2 | 1220 | 1243 | 1200 | 1223 | 1231.5 | 5.553125
1 | 1297 | 1320 | 1277 | 1300 | 1308.5 | 5.071875

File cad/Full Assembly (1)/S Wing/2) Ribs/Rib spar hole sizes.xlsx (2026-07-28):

Spar num | length min | m spar d w/o reinforcement | m spar d w reinforcement | length max | m spar d w/o reinforcement | m spar d w reinforcement | m spar avg
root | 0 | 28 | 30.7
13 | 100 | 27.57584615 | 30.27584615 | 123 | 27.47829077 | 30.17829077 | 30.22706846
12 | 177 | 27.24924769 | 29.34924769 | 200 | 27.15169231 | 29.25169231 | 29.30047
11 | 277 | 26.82509385 | 27.72509385 | 300 | 26.72753846 | 27.62753846 | 27.67631615
10 | 374.75 | 26.41048346 | 27.01048346 | 397.75 | 26.31292808 | 26.91292808 | 26.96170577
9 | 488.5 | 25.92800846 | 26.52800846 | 511.5 | 25.83045308 | 26.43045308 | 26.47923077
8 | 602.25 | 25.44553346 | 26.04553346 | 625.25 | 25.34797808 | 25.94797808 | 25.99675577
7 | 700 | 25.03092308 | 25.63092308 | 723 | 24.93336769 | 25.53336769 | 25.58214538
6 | 788.5 | 24.65554692 | 25.25554692 | 811.5 | 24.55799154 | 25.15799154 | 25.20676923
5 | 877 | 24.28017077 | 24.88017077 | 900 | 24.18261538 | 24.78261538 | 24.83139308
4 | 984.667 | 23.82349705 | 24.42349705 | 1007.667 | 23.72594166 | 24.32594166 | 24.37471936
3 | 1092.334 | 23.36682333 | 23.96682333 | 1115.334 | 23.26926794 | 23.86926794 | 23.91804563
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

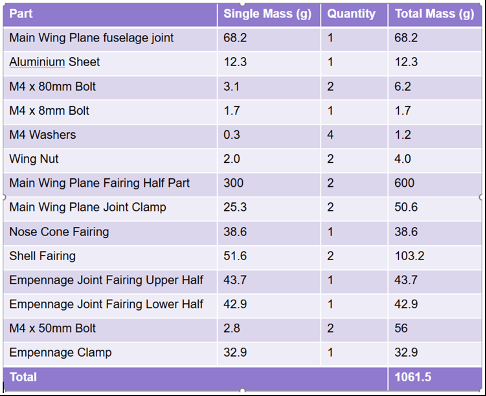
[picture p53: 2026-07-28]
figures/structures/subassembly-mass-table.png

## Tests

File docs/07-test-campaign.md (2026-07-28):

# 07 · Test Campaign

[← Manufacturing & integration](06-manufacturing-and-integration.md) · [Next: Project management & risk →](08-project-management-and-risk.md)

---

Three test events, each answering a different question.

| Test | When | Question | Result |
|---|---|---|---|
| Graphite Goose | TB-1 | Do the joints work as predicted at limit load? | Pass — behaved as analysed |
| Ultimate load test | 5 Mar 2025 | Does the airframe survive past ultimate load? | Pass to **813 N**, then failed in an unpredicted mode |
| Wind tunnel | TB-2 | Do the fairings reduce drag? | **Inconclusive** — the configuration could not answer it |

---

## 1 · Graphite Goose

A representative prototype assembly loaded to limit, with reactions applied at
the forward fuselage CG and empennage spar positions to reproduce Load Case 1
(requirement 3.2.6.a).

Everything fitted, and the structure behaved as the TB-1 analysis predicted.
This is worth flagging for a reason that only becomes clear later: **in this
test all parts assembled properly and the structure was correctly restrained.**
In the ultimate load test neither was true — and the two tests gave different
failure behaviour partly because of it.

---

## 2 · Ultimate load test

The ultimate load test station

*Load test station, 5 March 2025. Clockwise from top left: the loaded airframe
in the rig; the LabVIEW acquisition showing deflection channels at port wing,
starboard wing, centre and empennage; the aircraft viewed from the front.*

### Load response

The airframe was loaded past the ultimate load case to **813 N**.

Load versus deflection

The relationship is **linear all the way to the ultimate load case** — no knee,
no progressive softening, no sign of anything yielding early. Fitted stiffness:
**74 N/mm** at the centre and **102 N/mm** at the empennage.

This directly satisfies requirement 3.2.5.a and validates the whole TB-1
analysis chain. Whatever went wrong afterwards, the aircraft was correctly
analysed for the modes that were analysed.

### The failure

Sensors were removed after the ultimate load was reached, to protect them.
Loading continued.

The recorded load then went **813 N → 804 N → 764 N**. A load drop with no
visible or audible event means something has yielded, but nothing was obvious
from outside. The aircraft was disassembled and inspected.

**The centre bar — RF 1.95, the predicted failure point — was undamaged.** It
was inspected specifically because it was expected to be the failure, and showed
no deformation at all.

The failure was **bolt shear-out through the PLA main wing joint clamp**:

Damage to the main wing joint clamp
Second view of the damage
Detail of the shear damage

*The wing nut has pulled down into the counterbore cavity and the bolt has begun
working through the remaining thin section of printed plastic.*

### Root cause: the wrong clamp was fitted

Two clamp variants existed, deliberately
([Detailed design](03-detailed-design.md)):

- **Wind tunnel clamp** — 8 mm counterbore for a flanged bronze bush
- **Structural test clamp** — no counterbore, solid material under the wing nut

**The wind tunnel clamp was fitted for the structural test.** Swapping it would
have meant disassembling the pod, and there was not enough time. So the aircraft
was loaded with a cavity directly beneath the wing nut. Under load the nut
dropped into that cavity and the bolt sheared down through the thin plastic
left below it.

The design anticipated this problem and solved it. The **build configuration
control** did not carry the solution through to the day. The correct part
existed and was not fitted.

### A second contributing factor

The structure had to be **cable-tied closed** for the test, because the FRF
attachment could not be assembled (see
[Manufacturing & integration](06-manufacturing-and-integration.md)). This
produced **uneven deflection between the two wings**. An asymmetrically
restrained structure does not distribute load into its joints the way the
analysis assumed, and plausibly contributed to the clamp failing when and where
it did. Gate 4 recorded the cable ties explicitly.

### Also inspected

The rest of the airframe was checked for further damage. The only other finding
was rough bores in the empennage joint — **left by the printing process, not by
the applied loads**, and initially mistaken for a failure. Everything else was
sound, confirming the TB-1 predictions.

### What this test is actually worth

It is easy to read "failed unexpectedly" as a poor result. It is not.

- The airframe **exceeded its requirement**, surviving past ultimate load.
- The analysis was **validated** for everything it covered — linear response,
  undamaged centre bar.
- The failure was **traced to a specific, correctable cause**: a known
  configuration difference that was not enforced under time pressure.

The genuinely valuable finding is the analysis gap it exposed. **No reserve
factor was ever computed for any 3D printed part** — the checks were classical
metallic joint checks, applied to an aircraft with printed plastic in a primary
load path. The test found the boundary of the analysis rather than a mistake
inside it. That is what tests are for.

---

## 3 · Wind tunnel entry

Fuselage tested at **20 m/s** (Re ≈ 4.1 × 10⁵, M = 0.058), fairings on and
fairings off, across a range of attack angles, on a six-component balance.

Fuselage drag with fairings fitted

**Headline number:** fairings-on averaged **+0.09 N** drag over fairings-off.

**Why that number cannot be read as a drag penalty:** seven repeat runs at 0°
give **σ = 0.34 N** run-to-run. The claimed difference is about a quarter of one
standard deviation of the noise floor — unresolvable. Consistent with that, at
some 0° trials fairings-on measured *lower* drag than fairings-off. The honest
statement is that the tunnel detected no difference in either direction.

**Why the test could not answer the question it was set:** the wings could not
be fitted (facility size), which removes the fairing's primary benefit — 100 mm
of exposed cylindrical spar — from the experiment while leaving its cost, extra
wetted area, fully present. With no wings, the fairing's sides were open and
flow crept inside. The vertical cutout needed to clear the tunnel mounts caused
further interference. And the payload pod dominated the drag signal throughout.

The full aerodynamic argument, and what the result does and does not support, is
in [Aerodynamics](05-aerodynamics.md).

**A structural observation from the same runs:** the **empennage oscillated
noticeably** throughout. Not a failure — loads were far from critical — but
oscillation drives fatigue and shortens component life. Remedies are discussed
in [Structural analysis](04-structural-analysis.md).

---

## Design review outcomes

Two formal gate reviews assessed the subassembly.

### Gate 3 — Design sign-off, 13 January 2025

**Strengths**
- Good innovation in the centre-spar locating screw

**Concerns**
- Mounting/securing of the empennage seemed unclear
- Some questions not answered strongly
- The main wing fairing profile *"seems very simplistic and the form profile
  looks to be non-optimum for aerodynamics… design appears quite unambitious
  compared to what might be possible for this new sub-assembly"*

### Gate 4 — Quality inspection, 18 February 2025

**Strengths**
- Aero profiles fit around the wing profile
- Provision made for fitting into the tunnel

**Concerns**
- Lack of integration planning with the rest of the UAV
- Design/execution somewhat ad-hoc
- Cable ties required to close structures

### Reading the reviews against what happened

The reviews were largely right, and specific enough to be actionable:

- **"Cable ties required to close structures"** — this is the FRF attachment
  problem, flagged in February, and it was still unresolved at the March load
  test where it contributed to uneven wing deflection.
- **"Mounting/securing of the empennage seemed unclear"** — the brass insert
  scheme was a fallback for insufficient internal volume, and remains untested
  under lateral load.
- **"Non-optimum for aerodynamics"** — fair, and traceable to a real cause:
  without an early full-vehicle CAD assembly, the fairing had to be drawn
  conservatively around geometry that kept moving.

One review comment deserves a partial rebuttal. **"Lack of integration planning
with the rest of the UAV"** does not match the evidence: every interface was
reviewed repeatedly, the aircraft assembled, and this team ultimately built the
company's full CAD assembly when the Technical Director did not. What the
inspection saw was the *visible residue* of one failed interface — the cable
ties — on a subassembly that was integrated more carefully than most. The
underlying failure there was late interface definition by others and lost build
knowledge within the team, not absent planning.

---

[← Manufacturing & integration](06-manufacturing-and-integration.md) · [Next: Project management & risk →](08-project-management-and-risk.md)

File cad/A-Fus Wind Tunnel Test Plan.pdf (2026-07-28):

## AVDASI2 Wind Tunnel Test Plan – Company A Fuselage

(Pod & Payload + HTP & Elevator + Joints & Fairings + VTP & Rudder + Avionics) Ae23350@bristol.ac.uk

## 1. Personnel

Suggestions (adapt as your group wishes, you may wish to allocate deputies for workload sharing and resilience):

- Experimental Aerodynamics Lead (EAL) – Lachlan Uttley
- Overall test planning, coordination, and safety
- Avionics Test Lead (ATL) - Reuben
- Avionic systems planning, data logging, avionics contingency planning.
- Bring Laptop
- Avionics Technical Operator (ATO) – Mido Jedda,
- FCS Installation and control
- Bring Laptop
- Wind Tunnel Technical Operator (WTTO) Ho Lun, (backup Alex Barlow)
- Tunnel operation on the day (will receive briefing at start of session), tunnel balance data logging.
- Test Imaging Lead – (TIL) Ethan Paterson
- Optical imagery (photos) of assembly in tunnel, key features (smoke, tufts, control surfaces, etc) as planned in advance with stakeholders.
- Public Engagement Lead (PEL) – Oliver Schulz
- Photography of engaging elements of test (coordinate with Test Imaging Lead, but also team photos etc.), draft suggested LinkedIn posts etc.
- Test Installation Team (TIT) [x4]– Jad El Badaoui, Mido Jedda, Jack from Pod, Sameer Alhindi

- Installation and removal of assembly in tunnel (note setup/changeover/setdown slots in test schedule). Briefing and support on the day.
- Test Support Runners (TSP) [x2]– Alp Tlabar, Alex Barlow
- Flexible roles on the day, as required. Shouldn’t actually be running in QB.
- Toilet contingency
- Observers
- Wider divisions may wish to observe tests, but we need to avoid overcrowding. ATLs/delegates should monitor space and rota observer attendance if required.

## 2. Test Pre-requisites & Setup

2.1 Avionics Checklist | Avionics – Failure procedure
Connect CubePilot to laptop via Wi-Fi
- should hear buzz noise to confirm connection
- if not: proceed through fail checklist
Using the UI (User Interface), attempt to move the HTP and VTP
- should observe movement in the respective mechanisms
- if not: proceed through fail checklist
- should observe pitch angle data being logged on laptop
- if not: proceed through fail checklist
Switch to RC, attempt to move the HTP and VTP
- should observe movement in the respective mechanisms
- if not: proceed through fail checklist
- should observe pitch angle data being logged on laptop
- if not: proceed through fail checklist

Check For Loose Wiring

- check if Wi-Fi is properly connected on the laptop
- check the CubePilot circuit is properly set up
- does red light on the BEC show?
- are wires plugged into the correct ports on the cube?
- check if Coms in the code are correct
- "Com7" for USB
connection or
"udp:0.0.0.0:14550" for
WiFi
- has the correct Com-port been input?
- did you connect and disconnect the cube after restarting the UI?
- check all JSD connectors

### 2.2 Fuselage Pre-requisites

Assemble wing fairings onto fuselage

- Ensure nuts tightened sufficiently onto bolt at back of fairing (won’t ping off)
- Force balance attachment point accessible for tightening
- Secure nose cone
Assembly HTP & VTP
- HTP and Clamp tightened to fuselage, elevator free to move
- Bottom servo tightened onto clamp
- Elevator mechanism nylock nuts touching linkages but not tight
- VTP secure
Assembly of pod
Check for loose parts
- Anything loose or malfunctioning may be glued

### 2.3 Test fittings

Test fittings and mounts found in consumables in M.003
- Ensure all tight and secure on build

Attach Safety wires in tunnel

### 2.4 Wind Tunnel Risk Assessment to be completed by all present

## 3. Test schedule

Test Installation – Friday 21st Feb
Time | Action | Description | Data Required | Personnel
1440-1520 | Assemble Fuselage, bring to tunnel | Arrive at AVDASI lab in time to assemble fuselage before 1500 Put Together HTP, VTP, Fairings and Pod. Sting attachment point tightened on. Check fuselage pre-requisites Check equipment list and bring backup equipment | | TIT
1520-1535 | Attach force balance and sting | Bring to wind tunnel, same location as A1 lab Attach Main Wing Joint to force balance through fairings. Attach Sting to empennage (will have to be in front of tailplane and rudder) Attach safety wires to build | | TIT
1540-1600 | Test Operation of mechanisms | Test operation of control surfaces (Elevator and rudder) Check avionics Pre-Requisites | | TIT

| | Check equipment list and bring backup equipment
1540-1600 | Adjustments | Ensure safety of setup (ask academics) Check calibration of CubePilot Remove sting and adjust internal masses of pod so that Fuselage sits at 0 pitch to save time for Monday. Reattach Sting | CubePilot Angles | TIT
1600 | Lab closes

Static Test – Monday 24th Feb (Sting attached)
Time | Action | Description | Data Required | Personnel
0800-0805 | Quick Briefing | Everyone must have Completed wind tunnel risk assessment Have correct safety equipment Recap - Full briefing about Safety, Schedule and Roles must have been read in advance | | All
0805-0815 | Initial Assembly Proving | Double check installation and operation. Low speed ‘Bedding in’ | | WTTO
0815-0825 | Data Verification & calibration | Check CubePilot mounted within pod is measuring correct angles. Ensure Force balance is logging correctly | CubePilot Angles Force logging data | WTTO, ATL

Essential Data Capture
0825-0835 | Flow Speed Test | Find Max Flow speed U0 Increase flow speed incrementally Is system ‘sufficiently robust’ (section 4) Fixed Pitch angle @ 0°, Fixed Yaw angle @ 0°, Sting Attached | Max flow speed allowable based on visual stability | All
0835-0845 | Test Yaw Angles | Test different Yaw angles Test Yaw @ 0°, 1°, 2° Is system ‘sufficiently robust’ (section 4) Fixed Flow Speed U0 Fixed Pitch angle @ 0°, Sting Attached | Wind tunnel Force Logging Data | All
0850-0905 | Test Pitch Angles | Test different Pitching angles Test Pitch angles in 5° increments @ -10°, -5°, 5° , 10°, 15°, 20° Is system ‘sufficiently robust’ (section 4) Fixed Flow Speed U0 | Wind tunnel Force Logging Data | All

| | Fixed Yaw angle @0°, Sting Attached
0905-0910 | Rudder deflection speed | Does Rudder meet required deflection speed and angles under load TIL video and imaging Fixed Flow Speed U0 Fixed Yaw angle @0°, Fixed Pitch angle @ Sting Attached | Realtime Video | All TIL
0905-0910 | Test Rudder deflections | Rudder at deflection 10°,25°, 35, 40° Observe moments If behind Schedule only test at full deflection Fixed Flow Speed U0 ‘ONLY at’Fixed Yaw angle @0°, Fixed Pitch angle @0°, Sting Attached | Wind tunnel Force logging data time@ 10:02:25 Negative also | All
0910-0920 | Elevator speed and deflections | Elevator at deflections 10°,20°, 30°,40, 45 Observe moments Fixed Flow Speed U0 ‘ONLY at’Fixed Yaw angle @0°, Fixed Pitch angle @0°, Sting Attached | Time 10:05:40 Negative also
0920-0930 | No Fairings test | Drag and smoke visualisation? Fairings Removed, Record changes Fixed Flow Speed U0 Fixed Yaw angle @0°, Fixed Pitch angle @0°, Sting Attached | Pitch angles from Cube Wind tunnel Force logging data (Video) | All
0920-0930 | Static test – Dynamic test change over | Remove sting from empennage Readjust internal masses in pod so that fuselage sits at 0° pitch Keep Fairings off | | TIT

Dynamic Test – Monday 24th Feb
Time | Action | Description | Data Required (Expected) | Personnel
| | | already stable in pitch Manual pitch disturbance damped return

0945-
0955

Elevator
deflections

Elevator locked at deflections by servo, see what happens to pitch
Test at low deflections to avoid slamming into floor

Fixed Flow Speed U0
Fixed Yaw angle @0°,
Sting Not attached

Pitch angles from Cube

Wind tunnel Force logging
data

Order of deflections
-5°
-10
0
-10 redone
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
0955-1005 | Fuselage deflection | PID tuning Hold fuselage at large pitch angle (big stick) then release. Visually see response Fixed Flow Speed U0 Fixed Yaw angle @0°, Sting Not attached Control Surfaces @0° deflection | Pitch angles from Cube Wind tunnel Force logging data | All
1010-1040 | PID Avionics System test | Activate automatic control system Elevators should adjust to conditions Should provide greater stability in wind Attempt to deflect? (big stick) Test Minimum Pitch Range (The UAV shall achieve a minimum pitch trim range (αmax-αmin) of 25º at a test speed of 10m/s) Fixed Flow Speed U0 Fixed Yaw angle @0°, Sting Not attached | Pitch angles from Cube Wind tunnel Force logging data Realtime video | ATL ATO All
1040-1100 | Smoke Visualisation test | Add smoke, observe flow over surfaces. TIL imaging Fixed Flow Speed U0 Fixed Yaw angle @0°, Sting Not attached | Pitch angles from Cube Wind tunnel Force logging data Realtime video | All

| | Automatic flight @0 pitch
1100 | Changeover with company B | Remove Build from tunnel Ensure all parts are collected and tunnel left tidy | TIT

### 3.2 If Time to spare

Yaw and pitch angle static test to higher resolution
- yaw every half°
- pitch every 3°

## 4. Data

### 4.1 Data Acquisition

- Do not delete any data even if it is believed to be ‘bad data’
- Ensure everything is logged
- WTTO will be briefed on the day on how to logging of force drag and moment
- ATO and ATL responsible for logging pitch and control surface deflections
- Connect USB to mission planner, download data flash logs after each test where it is required

### 4.2 Relevant Spec 4.2.1 Fuselage

- The UAV shall achieve a minimum pitch trim range (αmax-αmin) of 25º at a test speed of 10m/s
- The UAV shall achieve for rudder deflection dCyaw force dδr > 2.3 and for yaw
angle dCyaw force dζ > 2
- The design of the pod shall be optimised to reduce aerodynamic drag. The drag shall be predicted via calculation. Pod load data shall be used to confirm the Pods aerodynamic performance.

### 4.2.2 Fairings

- Fairings shall be removeable, where practical, to enable their aerodynamic contribution to be isolated during Wind Tunnel testing.
- The fairings, as described in 2.6, shall reduce aerodynamic drag of the UAV at all flight speeds and angles of attack.

### 4.2.3 Static

- Systems shall be sufficiently robust to withstand, without requiring emergency/reactive modifications, a full range of rotation, while the fuselage is held fixed at a pitch angle of zero degrees, under wind tunnel testing conditions of wind speeds up to 20 meters per second.

### 4.2.4 Sensing

- Flight data, including but not limited to wind speed (from wind tunnel equipment), aerodynamic loads (from tunnel balance, fuselage pitch angle (from FCS and/or tunnel), elevator and rudder angles (from mechanism conversion curve or selected device), pitch control behaviour, and static pressure (from wind tunnel and wing taps (differential)) shall be logged
- Logging of all data should be at minimum 5Hz and ideally at >20Hz

### 4.2.4 Control

- The elevator shall be capable of deflection within an angle range of [-45,+45]° degrees with respect to the HTP aerofoil mean line.
- The elevator shall be capable of achieving the commanded positions within one degree under loading conditions up to the ultimate design load
- The elevator shall transition between maximum and minimum elevator angle less than 1.5 seconds.
- Pitch angle demand via TMS in 'automatic' flight using a PID controller. The controller shall be able to automatically adjust the elevator deflection to achieve the commanded pitch angle.
- The rudder shall be capable of rotation within an angle range of [-40,+40]° degrees with respect to the VTP aerofoil mean line.
- The rudder shall be capable of achieving the positions to within one degree of demanded angle, under loading conditions up to the ultimate design load.
- The rudder control system shall provide rudder angle demand via RCS in 'manual flight'.

### 4.3 Expected data

### 4.3.1 yaw angle static test. VTP is using NACA 0012. Polars using approximate Re value

of 2x10⁵ are below on left and a graph plotted by VTP of small angles of attack on the right

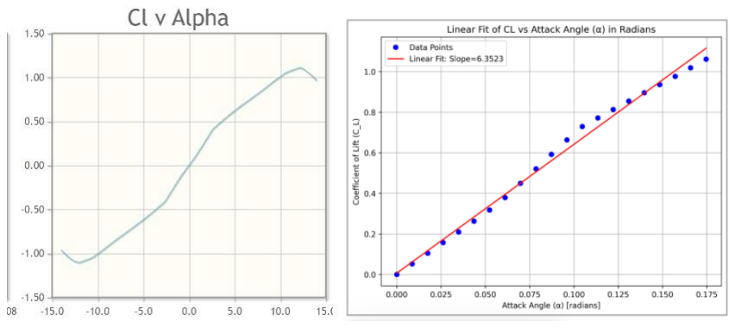
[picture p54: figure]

Expecting roughly linear increase in Cl at low Angles of Attack corelating to a linear increase in yawing moments as yaw increases.
Predicted rate of change of yawing moment with respect to yaw angle:

∂Cyaw force
∂ζ = 3.2
(Per radian)
VTP ac at 875mm from centre giving

∂Cyaw moment
∂ζ = 2.8

(Per radian)
As yaw increases expecting slight increase in drag at low angles.

### 4.3.2 Pitch angle static test

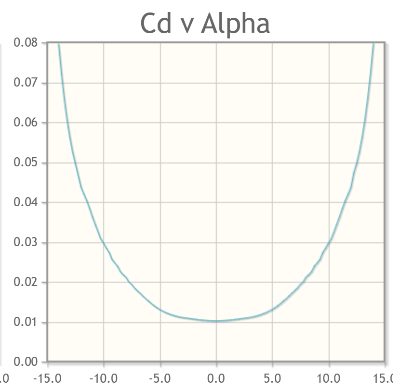
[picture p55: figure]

HTP is also using NACA 0012 airfoil. Polars using approximate Re value of 2x10⁵

:

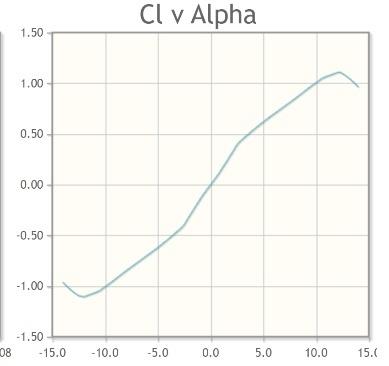
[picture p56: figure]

As Pitch increases expecting roughly linear increase in lift produced by tailplane until separation at around 10° where it is expected to curve off. This corelates to a linear and small increase in lift and a larger increase in pitching moment before separation. HTP team predicted maximum Cl and therefore pitching moment at around 10° AoA Tailplane lift gradient calculated as:

a1 =

dCl
α

= 3.88
(per radian)
Tail Plane around 860mm from force balance

dCpitcℎing moment
α

= 0.835
(per radian)

### 4.3.3 Rudder deflection

Calculated rate of change of with respect to rudder deflection by VTP team:

∂Cyaw force
∂δ = 2.304

∂Cyaw moment
∂δ = 2.016

Predicted linear relationship at small angles, expect it to curve of at larger angles of deflection when there will be flow separation

### 4.3.4 Elevator Deflection Dynamic test

Calculated rate of change of lift of tailplane and therefore pitching force. Expect linear relationship between force and therefore pitching moment in at small deflections before separation
Pitch angles assumed to be linear to pitching force.

### 5. Equipment

Fuselage build equipment | Avionics Equipment
- Fuselage
- Main wing joint
- Wing fairing
- Bolts and nuts..
- Nose Cone
- Empennage joint
- 2xbolts through fuselage with wing nuts
- 3xfairings to clamp
- HTP
- Tailplane
- Mechanism attached to
bottom joint under fuselage
- VTP
- Test fittings found in consumables (M.003)
- 6dof force balance mount
- Sting attachment point (no spares do not lose)
- Backup Equipment and tools
- Main wing joint fastener
- Spare bolts and nuts for build
Tape & glue
- Laptop x2
- charger
- CubePilot + circuit
- BEC circuit
- Cube power cable
- Wi-Fi chip
- RC chip
- RC controller
- Long emergency USB cable
- Power cable
- Backup equipment
- Wires
- wire strippers
- Tape

### 5.3 Equipment provided by staff

- Wind tunnel, 7x5ft working section, including 6dof balance, measuring system, and appropriate attachments.
- Power supply (single variable voltage), e-stop, wires sufficient to run from test control table into tunnel. XT60 female connector at tunnel end.
- USB extension (USB-A female to male), 5m powered – sufficient from tunnel to table.
- Briefings and supervision as appropriate, but student teams will lead own tests.

### 6. Safety

Everyone present to read and complete risk assessment, published in advance

Be aware of your surroundings, you are responsible for your own build
The Wind Tunnel Lab is a professional research environment, all student-researchers are responsible for their safety and conduct, and the safety of others.
Risk assessment will be published in advance, all members to read, query where necessary, raise any additions as required.
Tests will be conducted under divisional leadership arrangements, however any necessary staff instruction will supersede these and must be promptly heeded. Staff will permit team autonomy where appropriate, but may intervene to support safety or effective outcomes.

### 7. Photography & other elements

- Photography of smoke visualisation of flow
- Photography of tufts
- Points of separation
- Changes in behaviour after changes in setup
- Essential Test photography and videography that can’t be logged
- required deflections and speeds
- Stability at flow speed
- LinkedIn photography

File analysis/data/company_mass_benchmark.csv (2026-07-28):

# Cross-company mass benchmark | AVDASI 2 2024-25. Three student companies built
# to the same requirement set. Source: company mass report (Figure 3.7 Weights).
assembly | albatross_kg | bluebird_kg | cropheed_martin_kg | notes
Port wing | 1.25 | 1.30 | 1.40 | includes avionics
Starboard wing | 1.50 | 1.30 | 1.25 | includes avionics
Fuselage | 2.10 | 2.25 | 2.70 | excludes fairings and payload
Fairings | 0.652 | 0.212 | 0.627 | fairings only

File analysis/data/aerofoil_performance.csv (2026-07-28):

# NACA 2414 port wing section | Re = 4.11e5 | M = 0.0582 (20 m/s | ISA sea level
# chord 0.30 m). Values as stated in Section 5.1.1 of the Team 08 A2 Technical
# Report. XFoil = inviscid/viscous 2D panel prediction; Tunnel = measured.
configuration | source | cl_max | cd_min
Clean (0 deg flap) | XFoil | 1.25 | 0.007
Clean (0 deg flap) | Wind tunnel | 1.00 | 0.030
Flap 30 deg | XFoil | 1.80 | 0.070
Flap 30 deg | Wind tunnel | 1.25 | 0.200

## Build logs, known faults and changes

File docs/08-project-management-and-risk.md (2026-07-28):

# 08 · Project Management and Risk

[← Test campaign](07-test-campaign.md) · [Next: Lessons learned →](09-lessons-learned.md)

---

I was one of Team 08's Project Managers and the **Fuselage Division Design Team
Manager**, so this section is largely my own work. It is also the section where
the project's real difficulties live — the engineering was rarely the hard part.

---

## Planning documents

Three documents, deliberately built to be **congruent** with one another. That
word is doing real work: a WBS, a Gantt and a network diagram are three views of
the same project, and if they disagree the team gets confused about which one is
true.

### Work breakdown structure

Decomposed the year into tangible tasks and assigned responsibility across the
specialisms within the team.

Work breakdown structure

### Gantt chart

A calendar view of durations, dependencies and deadlines, giving early sight of
bottlenecks. It was maintained as a live document across the year.

Full year Gantt chart

For the design and build phase (weeks 7–17) it was refined substantially:
tasks broken down to a feasible granularity, **slack deliberately built in**,
and — importantly — **tasks assigned to named individuals** rather than to the
team collectively.

Design and build phase Gantt

*Phase 3–6 detail with hour estimates per task. Assigning tasks to individuals
was the single most effective change made to the plan all year.*

### Activity-on-node network diagram

Mapped the interdependencies and identified the **critical path**.

Team network diagram

At company level, the Design Team Managers built **divisional** network diagrams
capturing dependencies across teams within a division.

Company fuselage division network diagram

These divisional documents were the mechanism linking team objectives to company
objectives — the layer that was otherwise missing.

---

## Critical path versus reality

This is the most instructive number in the whole project management effort:

| | Hours |
|---|---|
| Critical path prediction | **48** |
| Lab hours actually clocked | **105** |
| | *plus all work done outside the lab* |

**The plan was out by more than a factor of two.** Not because the task
estimates were bad — because the network diagram modelled the *wrong
dependencies*.

The diagram captured dependencies **within Team 08**. It did not capture the
dependency that actually governed the schedule: Team 08's tasks waiting on
**other teams' designs**. A joint cannot be dimensioned until the spar it holds
is dimensioned. That dependency is invisible on a team-level AoN diagram, and it
was the binding constraint all year.

The float analysis inherited the same blind spot. Internal tasks were correctly
sorted into "can slip" and "cannot slip". Neither category anticipated an
external change forcing a completed task to be redone.

**The lesson generalises well beyond this project.** For a team sitting
downstream of six others, a plan that models only its own internal dependencies
is not a schedule — it is a best case that assumes the rest of the world holds
still.

---

## Team integration into the company

Team 08's designs depended on measurements and fittings from other teams across
the fuselage and wing divisions, which made the phase *after* the Gate 3 design
freeze unexpectedly difficult.

The pattern was sharp and consistent:

- **Main wing joint and clamps** — counterpart geometry fixed early → almost no
  revision, easy updates
- **Empennage joint** — HTP, VTP and avionics dimensions arrived late, some
  after design freeze → repeated redesign

The team's conclusion was that **proactive engagement beat passive information
acquisition**, decisively. Waiting to be told a dimension meant learning it in a
lab session, weeks after it was needed.

A structural observation also came out of this: given how many subassemblies
depended on Team 08's parts, describing the team as sitting *within* the
fuselage division understated its role. Its actual position was
**inter-divisional**.

### Design freeze

As Design Team Manager I imposed a **company-wide design freeze**. It was
necessary — some teams, notably VTP, were still finalising after Gate 3, which
meant Team 08 was still redesigning interfaces to parts that were supposed to be
settled.

It should have come earlier. By the time it was enforced, much of the rework it
was meant to prevent had already happened.

---

## Risk management

A full risk assessment was completed for Gate 1 and maintained as a **live
document** — matters more than it sounds, since a risk register written once and
filed is an artefact rather than a tool.

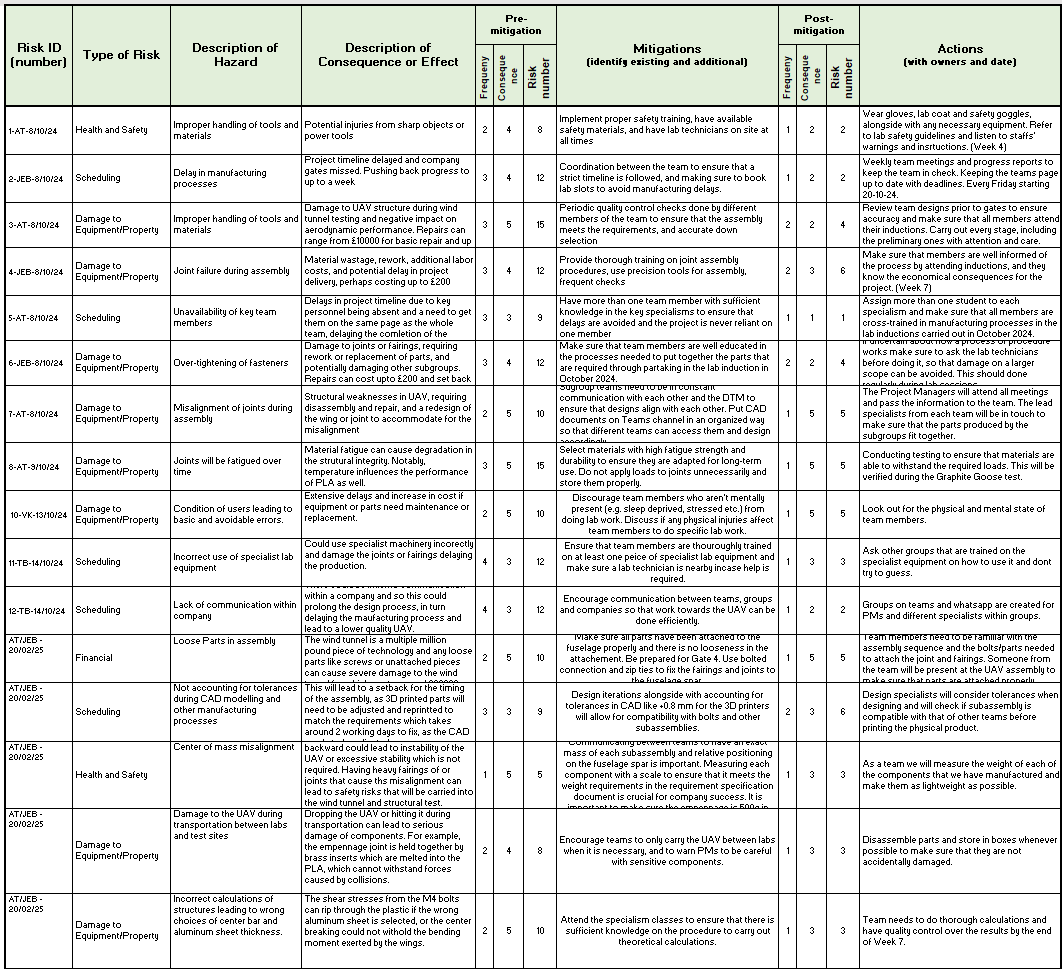
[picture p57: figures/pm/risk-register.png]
Risk register


*Pre- and post-mitigation risk numbers with owners and dates. Entries carry
author initials and the date raised.*

Risk rating matrix

Risks were scored on frequency × consequence, giving a risk number used to
prioritise effort. The register drove two concrete behaviours that paid off:
mandatory attendance at lab inductions and specialist lectures, and a habit of
asking lab technicians directly when something was uncertain.

### What the register caught

Equipment damage and scheduling were correctly identified as the dominant risk
categories. Risk 3 — damage to the wind tunnel during testing — was mitigated
by emphasising secure attachment procedures, and no tunnel damage occurred.

### What it missed, and why

**3D printing failures.** Not anticipated at all, because nobody on the team had
enough experience with additive manufacture to know what its failure modes look
like. This is a structural weakness of risk assessment done by novices: **you
cannot enumerate risks in a process you have not used.**

**Poor fairing assembly during structural testing.** The register assumed
thorough familiarity with assembly procedures. In the event, the team member
present at the test was the only one who had missed the practice assembly. The
register recorded an *assumption* about team knowledge rather than a *mechanism*
for ensuring it.

**Mitigations that were too vague to act on.** Several entries lacked the
specificity to be useful under time pressure. "Ensure correct assembly" is not a
mitigation; "verify clamp part number against the test configuration sheet
before loading" is. The clamp that failed at the load test is precisely the case
a specific mitigation would have caught.

**Scheduling risk was under-weighted.** The register leaned heavily toward
damage-to-property risks. Scheduling was the risk that actually materialised,
repeatedly and expensively.

### Company-level failures

Limited cross-team communication on technical issues produced late-stage
surprises: delays finishing the full-company CAD assembly led to **mismatched
dimensions during physical assembly**, difficulty fitting payload rings to
fairings, and a **misaligned centre of mass** that forced further revision.
Continued design changes after Gate 3, combined with poorly coordinated slack
between teams, stretched the timeline directly.

---

## What I would change

**Model external dependencies explicitly.** Flag on the Gantt and the network
diagram every internal task that depends on another subassembly, and treat those
as the critical path they actually are. This alone would have closed most of the
48 vs 105 hour gap.

**Treat PM documents as team tools, not deliverables.** They were produced,
submitted, and then under-used. Discussed weekly, they would have driven
behaviour instead of documenting it.

**More milestones than just the gates.** The gates were the only formal feedback
points, so problems surfaced at intervals of months. Intermediate milestones
would have shortened that loop.

**Build the risk register with people who have done it before.** Lab technicians
and students from the year above have seen the failure modes this team could not
imagine. The 3D printing gap was entirely foreseeable by someone with printing
experience.

**Add a financial dimension.** Real engineering is driven by cost. An internal
currency — buying lab hours, paying for print time — would force the trades that
were instead made implicitly. The fairings would not have been printed in PLA if
print time had a price attached.

**Use a live collaborative platform.** A shared tracker with cross-divisional
dependency visibility, and simple traffic-light status reporting, would have made
inter-team blockages visible while they could still be acted on. A Kanban board
did serve this purpose for part of the year and worked well while it was
maintained; it lapsed when the directors stopped posting, and cross-team
communication degraded with it.

---

[← Test campaign](07-test-campaign.md) · [Next: Lessons learned →](09-lessons-learned.md)

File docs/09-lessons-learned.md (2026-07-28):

# 09 · Lessons Learned

[← Project management & risk](08-project-management-and-risk.md) · [My contribution →](my-contribution.md)

---

The subassembly worked. The aircraft assembled, survived past its ultimate load
case, and went through a full tunnel entry. What follows is what I would do
differently, written to be useful rather than flattering.

---

## 1 · Draw the analysis boundary around the aircraft, not around the method

**What happened.** Eight reserve factors were computed, all sound, all
conservative. The airframe then failed in a mode with no reserve factor at all —
bolt shear-out through printed PLA.

**Why.** The checks were classical metallic joint checks: bearing, tension,
shear, cleavage, prying, bending. That was the taught method and it was applied
correctly. But requirement 2.5.2.a treats printed plastic as a non-structural
former, so PLA parts fell outside the analysis by definition — even after one of
them ended up in a primary load path.

**The generalisable lesson.** An analysis scope inherited from a *method* will
quietly stop matching the *artefact* as the design evolves. The question to ask
before a test is not "did I do the checks correctly" but "**is there any load
path I have not checked at all**". The second question would have found this.

## 2 · Configuration control is a real engineering deliverable

**What happened.** Two clamp variants were correctly designed for two different
test configurations. The wrong one was fitted for the load test, because
swapping it meant disassembling the pod and time had run out. The aircraft
failed at exactly that part.

**Why it matters.** This was not a design error. The design anticipated the
problem and solved it. What failed was the process that carries the right part
to the right test on the right day.

**What I would do.** A written build configuration sheet per test, checked
against fitted part numbers before loading, signed off by someone who is not the
person who fitted them. That is a ten-minute control that would have prevented
the project's only structural failure.

## 3 · Do not let one material decision become permanent

**What happened.** 100% FDM PLA, decided early. Fairings ended up at **3.1× the
mass of the lightest company** and **11.85% of all-up UAV mass**, on an aircraft
where mass drives take-off from a short rural runway.

**The nuance.** The decision was correct when it was made — fast iteration and
complex curves were genuinely needed, given how much neighbouring geometry
moved. The error was never revisiting it. Some parts, like the nose cone
fairing, were geometrically stable from early on and paid for a flexibility they
never used.

**What I would do.** Review material choice per-part at design freeze, and split
the set: keep additive for parts still moving, move stable geometry to foam or
formed sheet. A hybrid was available — a printed exoskeleton under a film
covering was discussed and never tried.

## 4 · Weighting a criterion is not the same as enforcing it

**What happened.** Weight came out of the pairwise comparison as one of the top
three criteria at **21%**. The delivered fairings were the heaviest of three
companies.

**Why.** The weighting informed concept *selection* and then stopped being used.
Nothing tracked mass against a budget during detailed design, so it drifted
without anyone noticing until the week-16 inspection preparation — by which
point rearranging other joints and fairings would have cost more time than
existed.

**What I would do.** Convert every top-weighted criterion into a **tracked
number with a budget and an owner**. A mass column reviewed weekly makes the
problem visible in week 4 rather than week 16.

## 5 · Plan the dependencies you do not control

**What happened.** The critical path predicted **48 hours**. The team clocked
**105 lab hours**, plus outside work.

**Why.** The network diagram modelled dependencies within Team 08. The dependency
that actually governed the schedule — waiting on six other teams' geometry — was
not on it.

**What I would do.** Put external dependencies on the diagram as first-class
nodes with owners and needed-by dates. For a team this far downstream, those
*are* the critical path.

## 6 · Freeze earlier, and mean it

**What happened.** I imposed a company-wide design freeze as Design Team
Manager. It was the right mechanism and it came too late — some teams finalised
after Gate 3, and the rework it was meant to prevent had largely already
happened.

**What I would do.** Freeze interfaces before geometry. Teams do not need a
finished VTP to commit to its root footprint. **Freezing the interface early
allows the part behind it to keep moving**, which is exactly the flexibility
everyone actually wanted.

## 7 · Build knowledge has to be transferred deliberately

**What happened.** A trial assembly on 3 March confirmed the FRF attachments
aligned correctly. At the structural test days later, the one team member
present was the only one who had missed that assembly. The joint could not be
fitted, cable ties were used instead, wing deflection went uneven, and Gate 4
recorded it.

**Why.** The parts were right. The knowledge of how to assemble them lived in
the heads of people who were not there.

**What I would do.** Photograph the assembly sequence during the practice build
and attach it to the part drawings. Ensure anyone attending a test has either
done the build or has the sequence in hand. The information cost nothing to
capture and its absence caused a visible failure.

## 8 · A risk register written by novices misses novel risks

**What happened.** 3D printing failures were not on the register, because nobody
had enough additive experience to know what its failure modes look like.

**What I would do.** Co-author the register with lab technicians and students
from the year above. They have seen the failures a first-time team cannot
imagine. And write mitigations specific enough to execute under pressure —
"ensure correct assembly" is not actionable; a part-number check against a
configuration sheet is.

---

## What went right, and why

Worth recording, because these were not luck:

**Structural analysis was done early, ahead of detailed design.** That gave the
design team limits to work inside rather than an audit to fail afterwards. It is
the main reason the aircraft passed its load test.

**Tolerance stack-ups were run for every printed part.** CAD nominal dimensions
do not survive contact with a printer, and this was recognised on the first
prints rather than the last. Parts generally fitted first time.

**The CAD was rebuilt when it needed rebuilding.** Abandoning a live-referenced
model mid-project and redrawing against derived sketches was expensive and felt
like lost ground. It unblocked the rest of the year.

**Interfaces were negotiated, repeatedly.** Being downstream of six teams forced
a discipline of asking rather than assuming. Integration became the
subassembly's strongest area — and when the Technical Director did not deliver
the company CAD assembly, this team was able to build it.

**The empennage joint doing double duty as its own fairing** was the best design
decision on the subassembly: it got most of the available aerodynamic benefit
for zero additional part count, on an argument about where the flow is already
turbulent rather than on aesthetics.

---

## The thing I would most want a reviewer to notice

The two most valuable findings in this project both came from the gap between
**what was analysed** and **what was built**:

- The stress analysis was correct and did not cover the aircraft.
- The design anticipated the clamp problem and the build did not carry the fix
  through.

Neither is an arithmetic mistake. Both are failures of *scope and process* — and
in my experience of this project, that is where engineering actually goes wrong.
The calculations were the easy part.

---

[← Project management & risk](08-project-management-and-risk.md) · [My contribution →](my-contribution.md)

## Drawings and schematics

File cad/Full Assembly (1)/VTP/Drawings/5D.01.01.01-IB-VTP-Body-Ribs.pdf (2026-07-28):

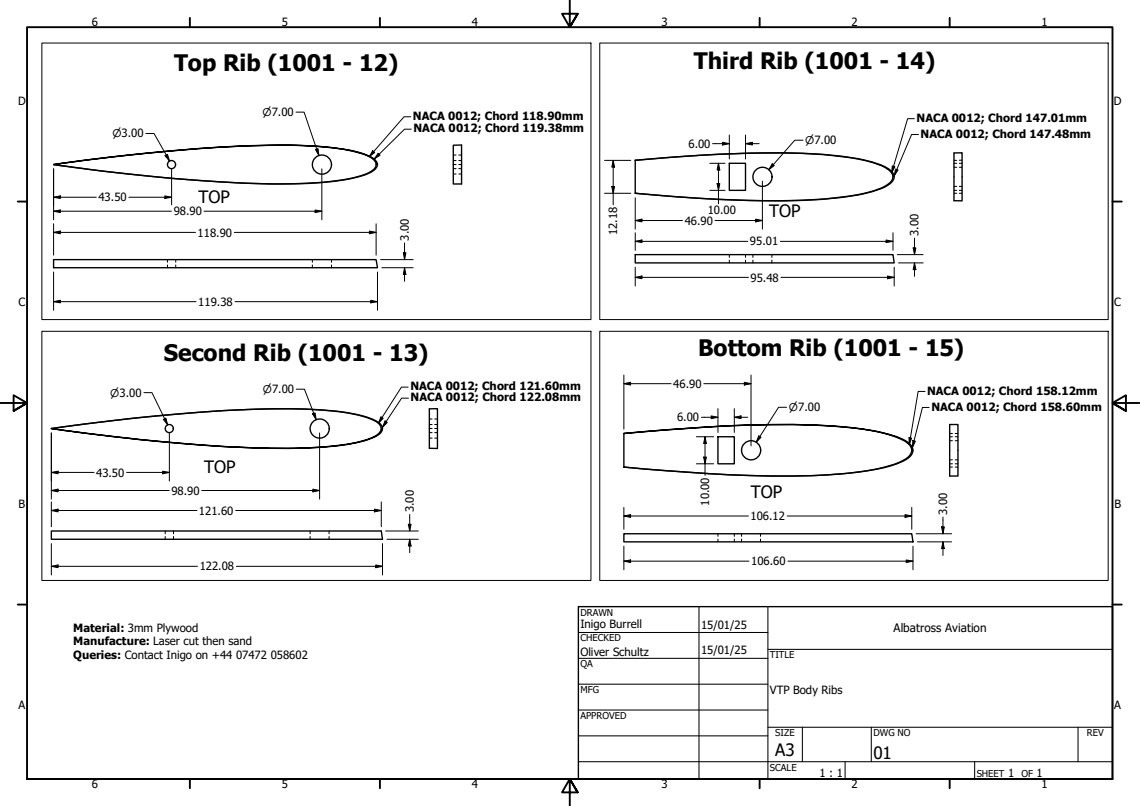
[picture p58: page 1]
NACA 0012; Chord 118.90mm NACA 0012; Chord 119.38mm; Top Rib (1001 - 12); NACA 0012; Chord 121.60mm NACA 0012; Chord 122.08mm; Second Rib (1001 - 13); NACA 0012; Chord 147.01mm NACA 0012; Chord 147.48mm; Third Rib (1001 - 14); NACA 0012; Chord 158.12mm NACA 0012; Chord 158.60mm; Bottom Rib (1001 - 15)

DRAWN Inigo Burrell | 15/01/25 | Albatross Aviation

Material: 3mm Plywood
Manufacture: Laser cut then sand
Queries: Contact Inigo on +44 07472 058602

CHECKED Oliver Schultz | 15/01/25

MFG

VTP Body Ribs

APPROVED

SIZE A3 | DWG NO 01 | REV

SCALE 1 : 1 | | SHEET 1 OF 1

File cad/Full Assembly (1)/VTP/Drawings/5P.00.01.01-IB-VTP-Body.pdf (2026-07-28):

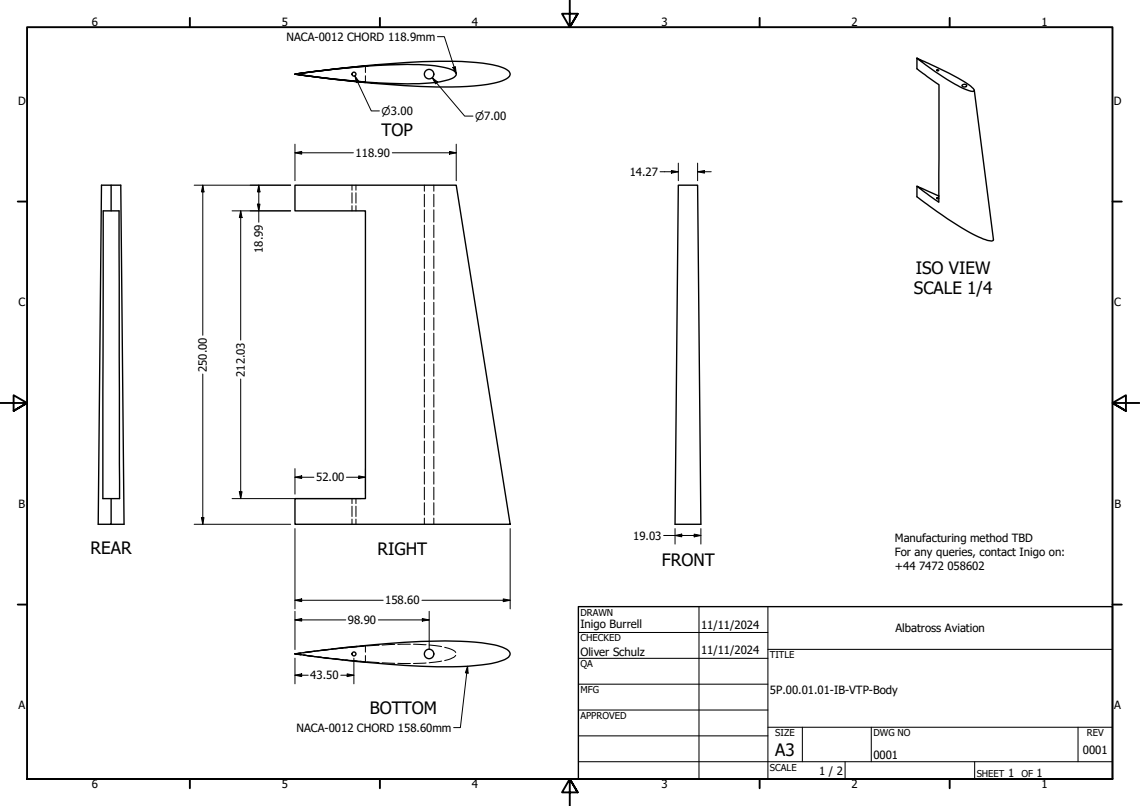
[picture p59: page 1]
ISO VIEW SCALE 1/4; NACA-0012 CHORD 158.60mm; NACA-0012 CHORD 118.9mm

Manufacturing method TBD
For any queries, contact Inigo on:

DRAWN Inigo Burrell | 11/11/2024 | Albatross Aviation

CHECKED Oliver Schulz | 11/11/2024

MFG

5P.00.01.01-IB-VTP-Body

APPROVED

SIZE A3 | DWG NO 0001 | REV 0001

SCALE 1 / 2 | | SHEET 1 OF 1

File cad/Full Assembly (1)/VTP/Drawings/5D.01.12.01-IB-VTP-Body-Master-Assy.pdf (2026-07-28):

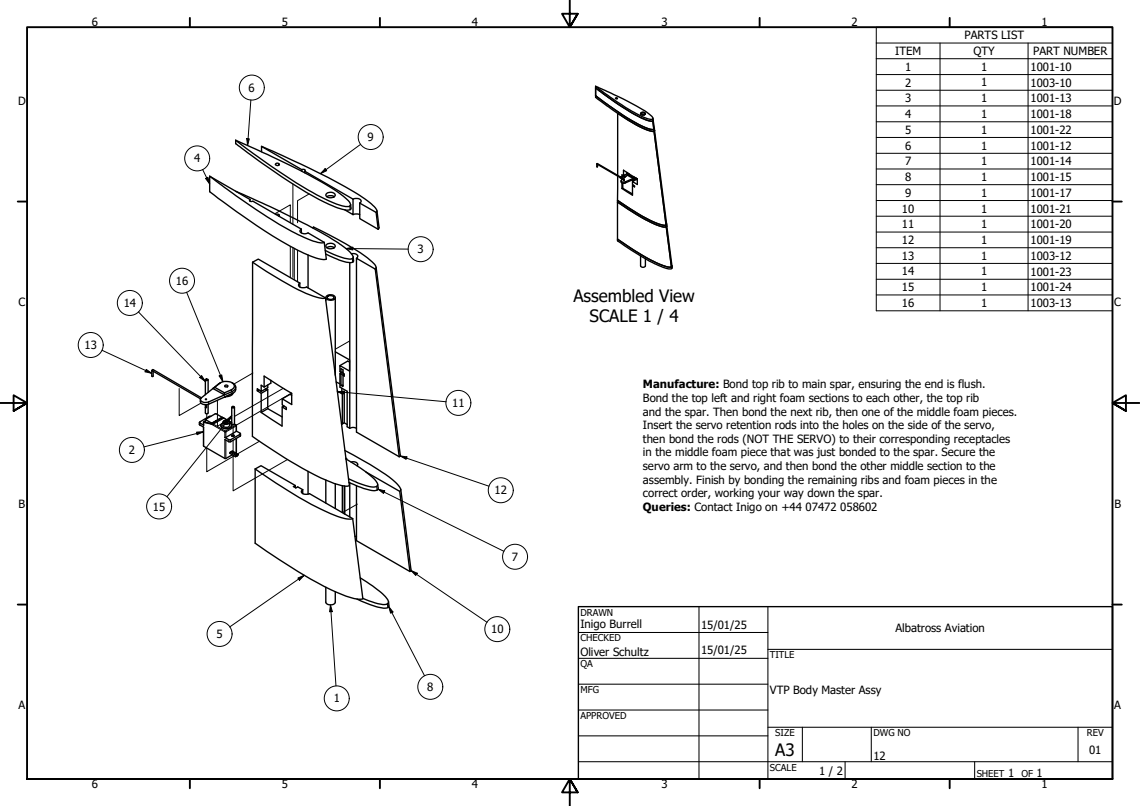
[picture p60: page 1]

I T E M | Q T Y | P A RT N U M B E R
1 | 1 | 1 0 0 1 -1 0
2 | 1 | 1 0 0 3 -1 0
3 | 1 | 1 0 0 1 -1 3
4 | 1 | 1 0 0 1 -1 8
5 | 1 | 1 0 0 1 -2 2
6 | 1 | 1 0 0 1 -1 2
7 | 1 | 1 0 0 1 -1 4
8 | 1 | 1 0 0 1 -1 5
9 | 1 | 1 0 0 1 -1 7
1 0 | 1 | 1 0 0 1 -2 1
1 1 | 1 | 1 0 0 1 -2 0
1 2 | 1 | 1 0 0 1 -1 9
1 3 | 1 | 1 0 0 3 -1 2
1 4 | 1 | 1 0 0 1 -2 3
1 5 | 1 | 1 0 0 1 -2 4
1 6 | 1 | 1 0 0 3 -1 3

D RA W N I n i g o B u r r ell Oliver Schult | 1 5 / 0 1 / 2 5 | Alb a t r o s s A v i a t i o n

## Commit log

2026-07-28 AVDASI 2 UAV: joints and fairings subassembly
    Full engineering portfolio for Team 08 (Joints & Fairings), Albatross
    Aviation, AVDASI 2 2024-25, University of Bristol.
    Contents:
    - docs/ nine-part write-up: requirements and traceability, concept
    downselection, detailed design, structural analysis,
    aerodynamics, manufacturing and integration, test campaign,
    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
    [1-copper.ipt, 1-soldermask.ipt, 16-copper.ipt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]
2026-07-29 Add tests for the chart pipeline, plus citation metadata
    The README claims every chart is regenerated from the CSVs and that nothing is
    hand-drawn. These tests hold that claim up rather than restating it: each dataset
    must parse, record its own provenance, and agree with the headline numbers quoted
    in the write-up.
    Writing them turned up two things worth fixing or recording.
    subassembly_mass.csv had no provenance at all, despite the README saying every CSV
    carries it. It now names the report table it transcribes and the figure that
    reproduces it. While adding that, the row count turned out not to match the
    README's "10 flight parts": the file holds 9 structural parts plus 5 fastener line
    i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
    [subassembly_mass.csv]
2026-07-29 Rebuild the README as the main visual account of the project
    The README used 3 of the 45 figures in the repository. Everything else was
    reachable only by opening one of the nine docs pages, which most readers will
    never do. It now uses 41, laid out so the engineering story is visible without
    clicking through.
    New sections carry the work that was previously text-only: the delivered part
    catalogue, the joints and the fairings as designed, concept downselection
    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
